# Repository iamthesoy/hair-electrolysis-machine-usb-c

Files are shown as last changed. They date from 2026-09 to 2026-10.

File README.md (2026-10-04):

# Hair Electrolysis Machine v4

### DIY electrolysis carries risk of permanent scarring if done improperly. If something goes wrong, only you are responsible.

electro2
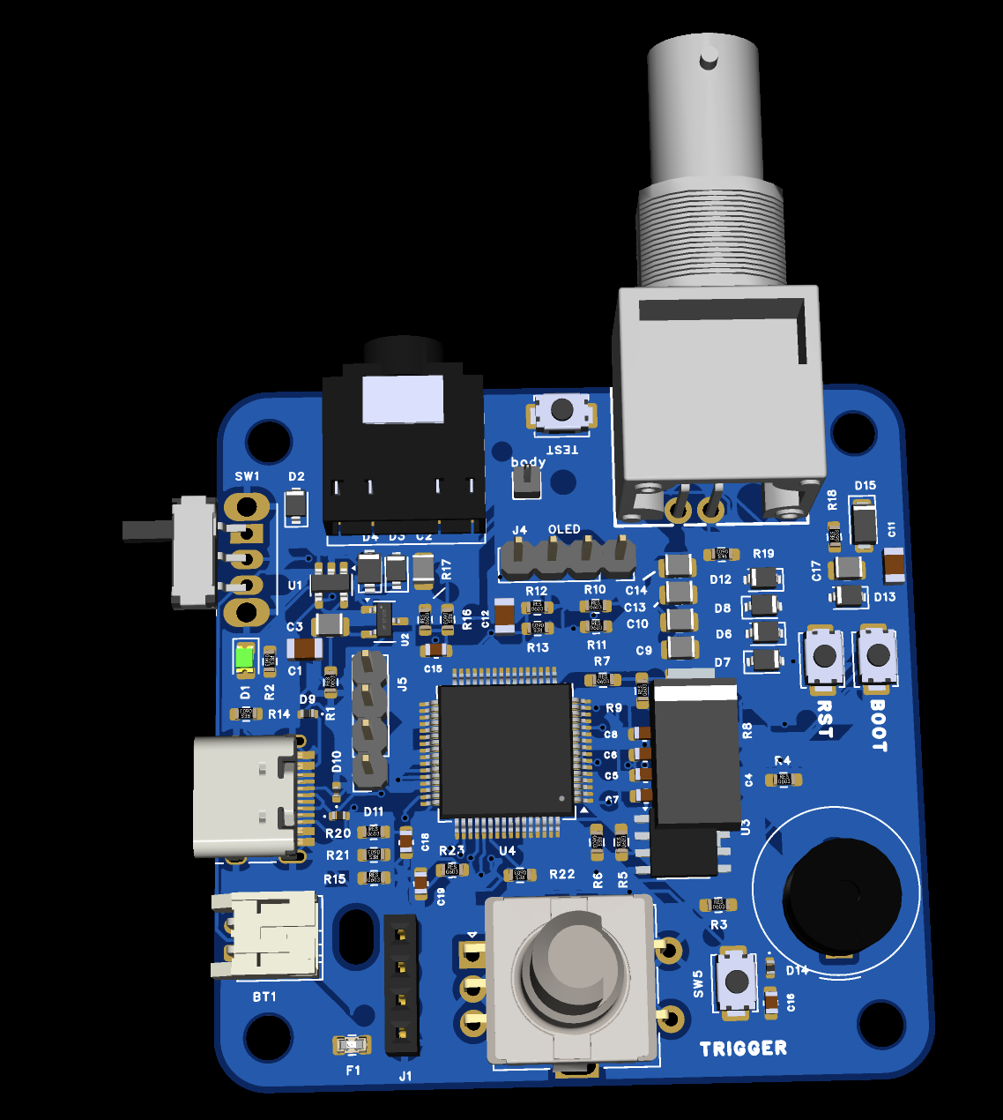
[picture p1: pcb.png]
electro3


---
This is a fork of zoemaestra's USB-C/STM32 fork of n3tcat's original. I've swapped a few connectors to make things sterex compatible as this is the hardware i'm used to, and uploaded some "compatible" sterex accessories for cost saving :) See zoe's readme below:

This is based on n3tcat's original design but redesigned around the STM32 to cut down the BOM and make the board single sided. Unlike v3.4, this board requires no soldering to assemble, just a 340mAh LiPo battery and a display which can just be plugged in. It is even cheaper and even easier to assemble at approximately £15/$20 per board!

You should really read the guide on how to order, assemble and use: https://imzoe.me/projects/electrolysis/electrolysis

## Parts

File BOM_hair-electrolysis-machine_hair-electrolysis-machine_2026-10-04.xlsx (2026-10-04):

No. | Quantity | Comment | Designator | Footprint | Value | Manufacturer Part | Manufacturer | Supplier Part | Supplier | LCSC
1 | 1 | HDR-M_2.54_1x1P | body | HDR-TH_1P-V-M_XKB_X4611WV-01I-C28D40
2 | 1 | Device_Battery_Cell | BT1 | Connector_JST:JST_PH_S2B-PH-K_1x02_P2.00mm_Horizontal | Battery_Cell |  |  |  |  | C16965
3 | 1 | Device_Buzzer | BZ1 | Buzzer_Beeper:Buzzer_TDK_PS1240P02BT_D12.2mm_H6.5mm | Buzzer |  |  |  |  | C76871
4 | 2 | Device_C_Small | C1,C5 | Capacitor_SMD:C_0603_1608Metric | 1uF |  |  |  |  | C15849
5 | 7 | Device_C | C2,C3,C9,C10,C13,C14,C17 | Capacitor_SMD:C_0805_2012Metric | 4.7uF |  |  |  |  | C1779
6 | 6 | Device_C_Small | C4,C6,C7,C8,C11,C16 | Capacitor_SMD:C_0603_1608Metric | 100nF |  |  |  |  | C14663
7 | 4 | Device_C | C12,C15,C18,C19 | Capacitor_SMD:C_0603_1608Metric | 100nF |  |  |  |  | C14663
8 | 1 | Device_LED | D1 | LED_SMD:LED_0805_2012Metric | LED |  |  |  |  | C84256
9 | 1 | Diode_SM4001 | D2 | Diode_SMD:D_SOD-323 | 1N4148WS |  |  |  |  | C2128
10 | 7 | Diode_1N5819WS | D3,D4,D6,D7,D8,D12,D13 | Diode_SMD:D_SOD-323 | 1N5819WS |  |  |  |  | C191023
11 | 2 | Diode_SMF18A | D5,D15 | Diode_SMD:D_SMF | SMF18A |  |  |  |  | C169433
12 | 4 | Diode_SM6T7V5A | D9,D10,D11,D14 | Diode_SMD:D_0402_1005Metric | ESD441 |  |  |  |  | C316049
13 | 1 | Device_Polyfuse | F1 | Fuse:Fuse_0805_2012Metric | 1A |  |  |  |  | C269104
14 | 4 | Mechanical_MountingHole | H1,H2,H3,H4 | MountingHole:MountingHole_3.2mm_M3 | MountingHole
15 | 1 | Mechanical_MountingHole | H5 | MountingHole:MountingHole_2.5mm | MountingHole
16 | 1 | Connector_Conn_01x04_Pin | J1 | Connector_PinHeader_2.54mm:PinHeader_1x04_P2.54mm_Vertical | Conn_01x04_Pin
17 | 1 | Connector_USB_C_Receptacle_USB2.0_16P | J2 | Connector_USB:USB_C_Receptacle_HRO_TYPE-C-31-M-12 | USB_C_Receptacle_USB2.0_16P |  |  |  |  | C165948
18 | 1 | Connector_Audio_AudioJack3_SwitchTR | J3 | Connector_Audio:Jack_3.5mm_CUI_SJ1-3525N_Horizontal | AudioJack2_Ground_Switch |  |  |  |  | C16684
19 | 2 | Connector_Conn_01x04_Pin | J4,J5 | Connector_PinSocket_2.54mm:PinSocket_1x04_P2.54mm_Vertical | Conn_01x04_Pin |  |  |  |  | C2718488
20 | 1 | 3GHz | probe | BNC-TH_DOSIN-801-0030 | 3GHz | DOSIN-801-0031 | dosinconn(德索五金) | C521205 | LCSC
21 | 1 | Transistor_FET_BSS138 | Q1 | Package_TO_SOT_SMD:SOT-23 | BSS138 |  |  |  |  | C8490
22 | 1 | Device_R | R1 | Resistor_SMD:R_0603_1608Metric | 2.7K |  |  |  |  | C13167
23 | 1 | Device_R | R2 | Resistor_SMD:R_0603_1608Metric | 1K |  |  |  |  | C21190
24 | 2 | Device_R | R3,R4 | Resistor_SMD:R_0603_1608Metric_Pad0.98x0.95mm_HandSolder | 100K1% |  |  |  |  | C25803
25 | 3 | Device_R | R5,R6,R7 | Resistor_SMD:R_0603_1608Metric_Pad0.98x0.95mm_HandSolder | 10K |  |  |  |  | C25804
26 | 2 | Device_R | R8,R9 | Resistor_SMD:R_0603_1608Metric_Pad0.98x0.95mm_HandSolder | 680R |  |  |  |  | C23228
27 | 3 | Device_R | R10,R11,R18 | Resistor_SMD:R_0603_1608Metric | 100R |  |  |  |  | C22775
28 | 2 | Device_R_Small | R12,R16 | Resistor_SMD:R_0603_1608Metric | 470K 1% |  |  |  |  | C23178
29 | 6 | Device_R_Small | R13,R17,R20,R21,R22,R23 | Resistor_SMD:R_0603_1608Metric | 100K 1% |  |  |  |  | C25803
30 | 2 | Device_R | R14,R15 | Resistor_SMD:R_0603_1608Metric | 5.1K |  |  |  |  | C23186
31 | 1 | Device_R | R19 | Resistor_SMD:R_0603_1608Metric_Pad0.98x0.95mm_HandSolder | 470R |  |  |  |  | C23179
32 | 1 | Switch_SW_SPDT | SW1 | Button_Switch_THT:SW_Slide_SPDT_Angled_CK_OS102011MA1Q | SW_SPDT |  |  |  |  | C131374
33 | 4 | Switch_SW_Push | SW2,SW3,SW5,TEST | Button_Switch_SMD:SW_SPST_TS-1088-xR025 | BTN |  |  |  |  | C720477
34 | 1 | Device_RotaryEncoder_Switch | SW4 | Rotary_Encoder:RotaryEncoder_Alps_EC11E-Switch_Vertical_H20mm | RotaryEncoder_Switch |  |  |  |  | C2991196
35 | 1 | Battery_Management_MCP73831-2-OT | U1 | Package_TO_SOT_SMD:SOT-23-5 | TP4054 |  |  |  |  | C668215
36 | 1 | Regulator_Linear_XC6206PxxxMR | U2 | Package_TO_SOT_SMD:SOT-23-3 | XC6206PxxxMR |  |  |  |  | C5446
37 | 1 | Amplifier_Operational_LM358 | U3 | Package_SO:SOIC-8_3.9x4.9mm_P1.27mm | LM358B |  |  |  |  | C1850238
38 | 1 | MCU_ST_STM32G0_STM32G0B1RBTx | U4 | Package_QFP:LQFP-64_10x10mm_P0.5mm | STM32G0B1RBTx |  |  |  |  | C5143679

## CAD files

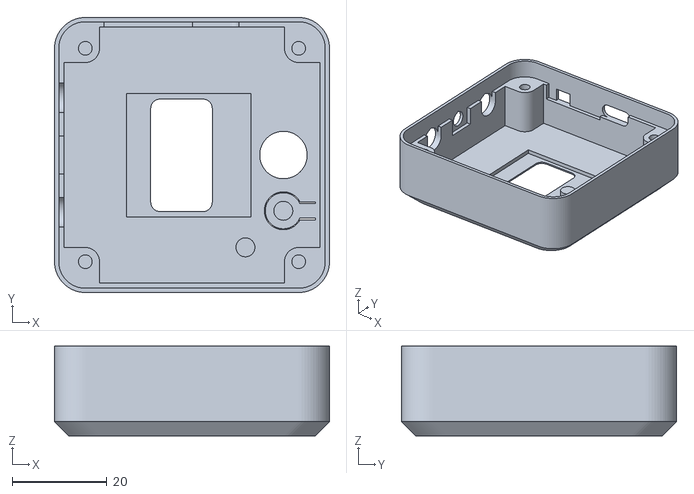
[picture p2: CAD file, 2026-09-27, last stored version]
3dprint/body_main.stl
58.0 x 58.0 x 18.9

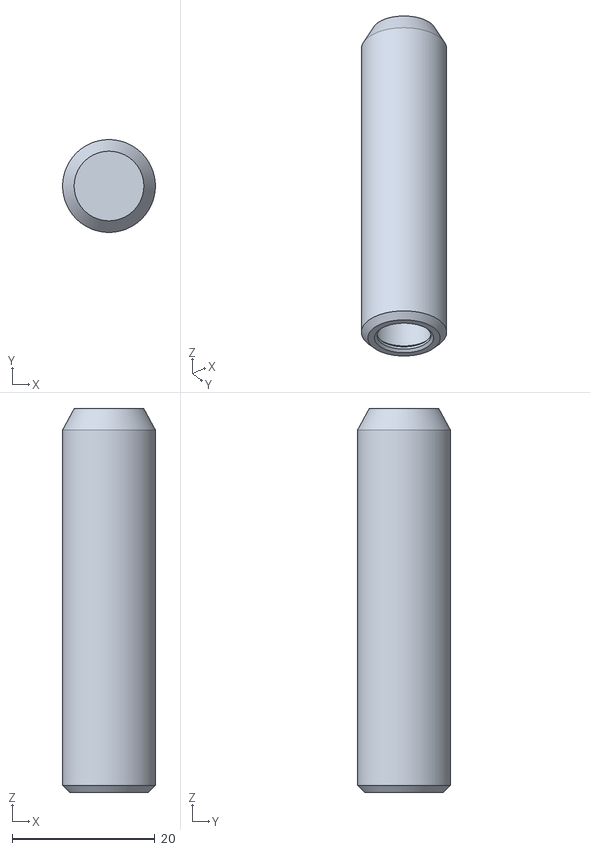
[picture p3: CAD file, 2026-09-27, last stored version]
3dprint/stylus_cap.stl
13.0 x 13.0 x 53.8

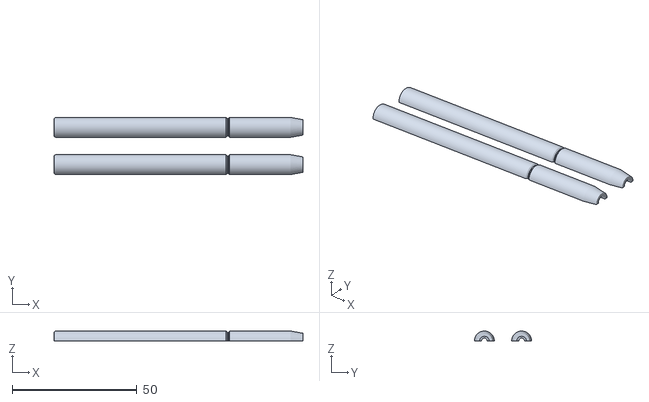
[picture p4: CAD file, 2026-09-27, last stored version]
3dprint/stylus_body.stl
100.0 x 23.0 x 4.00

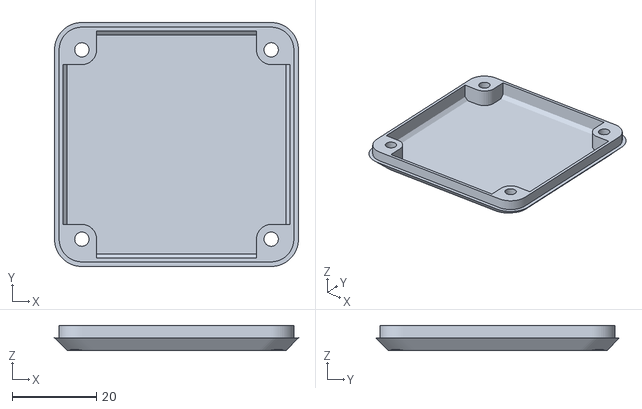
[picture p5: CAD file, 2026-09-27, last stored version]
3dprint/body_bottom.stl
58.0 x 58.0 x 6.00

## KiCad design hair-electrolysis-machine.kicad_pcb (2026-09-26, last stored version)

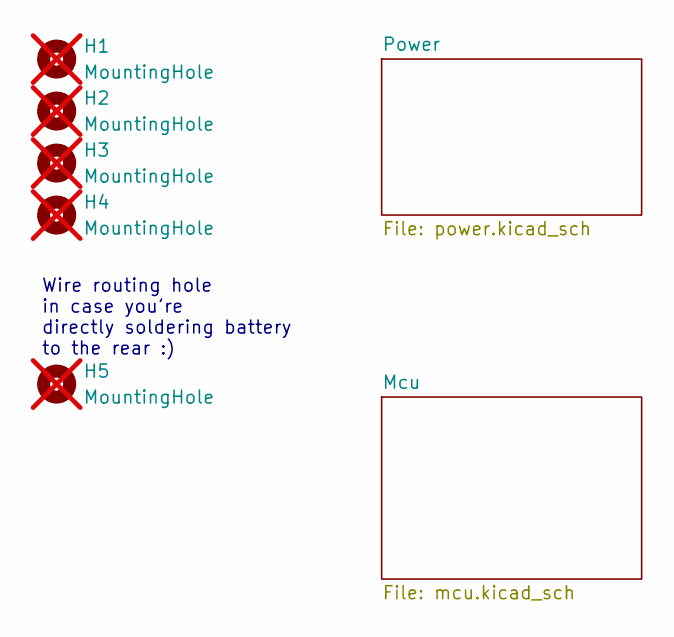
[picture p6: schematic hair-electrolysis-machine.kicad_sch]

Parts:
H1, H2, H3, H4: MountingHole; MountingHole_3.2mm_M3; not fitted
H5: MountingHole; MountingHole_2.5mm; not fitted

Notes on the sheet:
Wire routing hole in case you're directly soldering battery to the rear :)

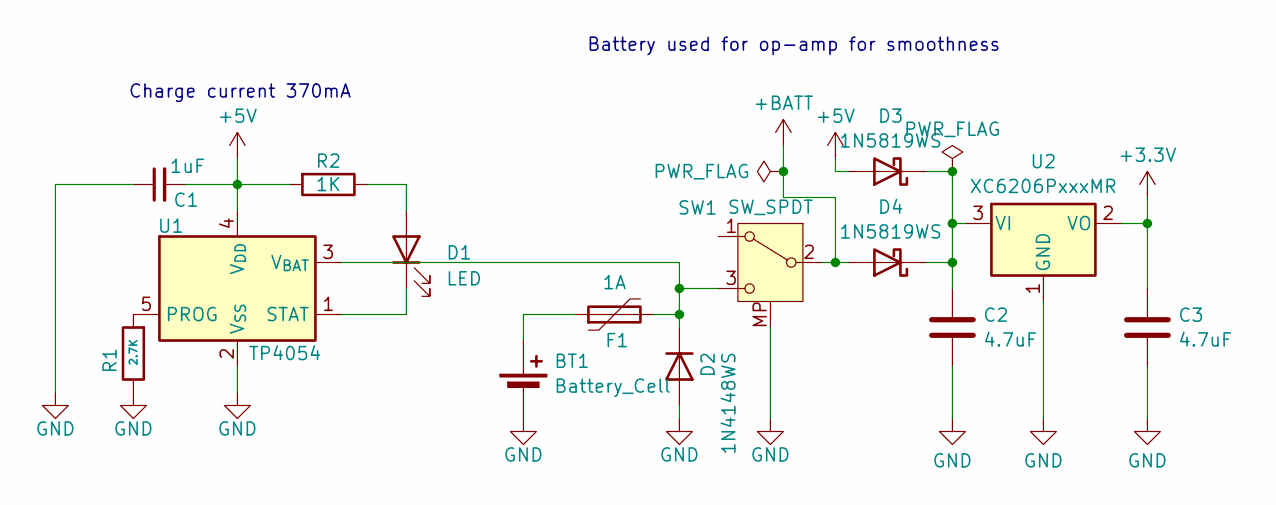
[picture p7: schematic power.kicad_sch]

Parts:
BT1: Battery_Cell; JST_PH_S2B-PH-K_1x02_P2.00mm_Horizontal; LCSC C16965
C1: 1uF; C_0603_1608Metric; LCSC C15849
C2, C3: 4.7uF; C_0805_2012Metric; LCSC C1779
D1: LED; LED_0805_2012Metric; LCSC C84256
D2: 1N4148WS; D_SOD-323; LCSC C2128
D3, D4: 1N5819WS; D_SOD-323; LCSC C191023
F1: 1A; Fuse_0805_2012Metric; LCSC C269104
R1: 2.7K; R_0603_1608Metric; LCSC C13167
R2: 1K; R_0603_1608Metric; LCSC C21190
SW1: SW_SPDT; SW_Slide_SPDT_Angled_CK_OS102011MA1Q; LCSC C131374
U1: TP4054; SOT-23-5; LCSC C668215
U2: XC6206PxxxMR; SOT-23-3; LCSC C5446

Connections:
+3.3V: C3.1, U2.2 (VO); also elsewhere on the board
+5V: C1.2, D3.2 (A), R2.2, U1.4 (V_{DD}); also elsewhere on the board
+BATT: D4.2 (A), SW1.2 (B); also elsewhere on the board
GND: BT1.2 (-), C1.1, C2.2, C3.2, D2.2 (A), R1.1, SW1.MP, U1.2 (V_{SS}), U2.1 (GND); also elsewhere on the board
unnamed: BT1.1 (+), F1.1
unnamed: D1.2 (A), R2.1
unnamed: D1.1 (K), U1.1 (STAT)
unnamed: D2.1 (K), F1.2, SW1.3 (C), U1.3 (V_{BAT})
unnamed: C2.1, D3.1 (K), D4.1 (K), U2.3 (VI)
unnamed: R1.2, U1.5 (PROG)

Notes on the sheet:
Charge current 370mA
Battery used for op-amp for smoothness

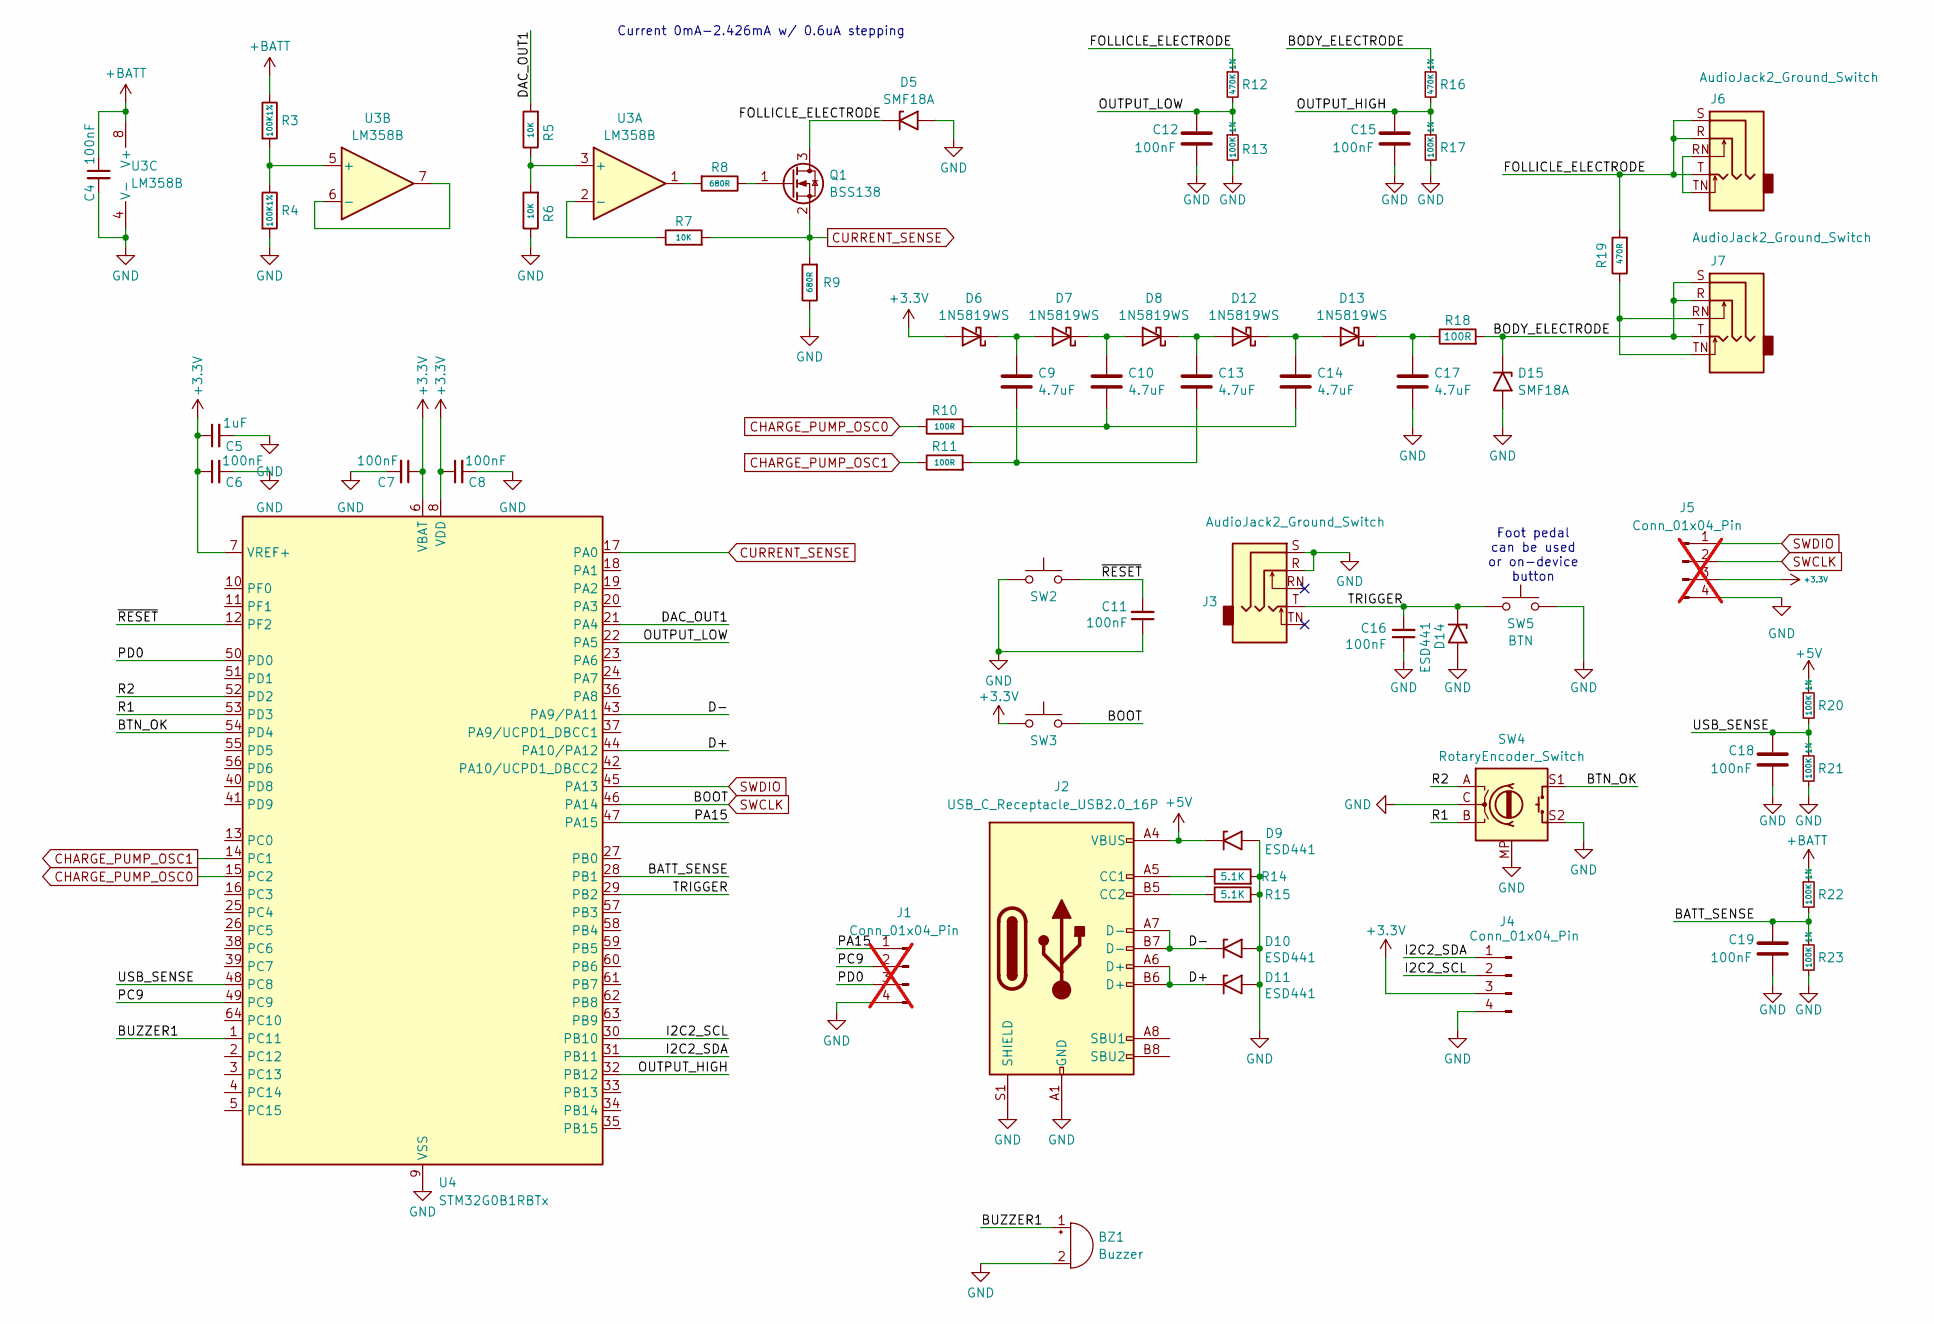
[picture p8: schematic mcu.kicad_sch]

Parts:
BZ1: Buzzer; Buzzer_TDK_PS1240P02BT_D12.2mm_H6.5mm; LCSC C76871
C4, C6, C7, C8, C11, C12, C15, C16, C18, C19: 100nF; C_0603_1608Metric; LCSC C14663
C5: 1uF; C_0603_1608Metric; LCSC C15849
C9, C10, C13, C14, C17: 4.7uF; C_0805_2012Metric; LCSC C1779
D5, D15: SMF18A; D_SMF; LCSC C169433
D6, D7, D8, D12, D13: 1N5819WS; D_SOD-323; LCSC C191023
D9, D10, D11, D14: ESD441; D_0402_1005Metric; LCSC C316049
J1: Conn_01x04_Pin; PinHeader_1x04_P2.54mm_Vertical; not fitted
J2: USB_C_Receptacle_USB2.0_16P; USB_C_Receptacle_HRO_TYPE-C-31-M-12; LCSC C165948
J3, J6: AudioJack2_Ground_Switch; Jack_3.5mm_CUI_SJ1-3525N_Horizontal; LCSC C16684
J4: Conn_01x04_Pin; PinSocket_1x04_P2.54mm_Vertical; LCSC C2718488
J5: Conn_01x04_Pin; PinSocket_1x04_P2.54mm_Vertical; not fitted
J7: AudioJack2_Ground_Switch; Jack_2.5mm_PJ242_6P_12x6.2x4mm_Horizontal; LCSC C431536
Q1: BSS138; SOT-23; LCSC C8490
R3, R4: 100K1%; R_0603_1608Metric_Pad0.98x0.95mm_HandSolder; LCSC C25803
R5, R6, R7: 10K; R_0603_1608Metric_Pad0.98x0.95mm_HandSolder; LCSC C25804
R8, R9: 680R; R_0603_1608Metric_Pad0.98x0.95mm_HandSolder; LCSC C23228
R10, R11, R18: 100R; R_0603_1608Metric; LCSC C22775
R12, R16: 470K 1%; R_0603_1608Metric; LCSC C23178
R13, R17, R20, R21, R22, R23: 100K 1%; R_0603_1608Metric; LCSC C25803
R14, R15: 5.1K; R_0603_1608Metric; LCSC C23186
R19: 470R; R_0603_1608Metric_Pad0.98x0.95mm_HandSolder; LCSC C23179
SW2, SW3, SW5: BTN; SW_SPST_TS-1088-xR025; LCSC C720477
SW4: RotaryEncoder_Switch; RotaryEncoder_Alps_EC11E-Switch_Vertical_H20mm; LCSC C2991196
U3: LM358B; SOIC-8_3.9x4.9mm_P1.27mm; LCSC C1850238
U4: STM32G0B1RBTx; LQFP-64_10x10mm_P0.5mm; LCSC C5143679

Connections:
+3.3V: C5.1, C6.1, C7.1, C8.1, D6.2 (A), J4.3, J5.3, SW3.2, U4.6 (VBAT), U4.7 (VREF+), U4.8 (VDD); also elsewhere on the board
+5V: D9.1 (A1), J2.A4 (VBUS), J2.A9 (VBUS), J2.B4 (VBUS), J2.B9 (VBUS), R20.1; also elsewhere on the board
+BATT: C4.1, R3.1, R22.1, U3.8 (V+); also elsewhere on the board
/Mcu/BATT_SENSE: C19.1, R22.2, R23.1, U4.28 (PB1)
/Mcu/BODY_ELECTRODE: D15.1 (A1), J7.R, J7.S, J7.T, R16.1, R18.2
/Mcu/BTN_OK: SW4.S1, U4.54 (PD4)
/Mcu/BUZZER1: BZ1.1 (+), U4.1 (PC11)
/Mcu/D+: D11.1 (A1), J2.A6 (D+), J2.B6 (D+), U4.44 (PA10/PA12)
/Mcu/D-: D10.1 (A1), J2.A7 (D-), J2.B7 (D-), U4.43 (PA9/PA11)
/Mcu/DAC_OUT1: R5.2, U4.21 (PA4)
/Mcu/FOLLICLE_ELECTRODE: D5.1 (A1), J6.R, J6.S, J6.T, Q1.3 (D), R12.1, R19.2
/Mcu/I2C2_SCL: J4.2, U4.30 (PB10)
/Mcu/I2C2_SDA: J4.1, U4.31 (PB11)
/Mcu/OUTPUT_HIGH: C15.1, R16.2, R17.1, U4.32 (PB12)
/Mcu/OUTPUT_LOW: C12.1, R12.2, R13.1, U4.22 (PA5)
/Mcu/PA15: J1.1, U4.47 (PA15)
/Mcu/PC9: J1.2, U4.49 (PC9)
/Mcu/PD0: J1.3, U4.50 (PD0)
/Mcu/R1: SW4.B, U4.53 (PD3)
/Mcu/R2: SW4.A, U4.52 (PD2)
/Mcu/TRIGGER: C16.2, D14.1 (A1), J3.T, SW5.2, U4.29 (PB2)
/Mcu/USB_SENSE: C18.1, R20.2, R21.1, U4.48 (PC8)
/Mcu/~RESET: C11.2, SW2.1, U4.12 (PF2)
CHARGE_PUMP_OSC0: R10.1, U4.15 (PC2)
CHARGE_PUMP_OSC1: R11.1, U4.14 (PC1)
CURRENT_SENSE: Q1.2 (S), R7.2, R9.2, U4.17 (PA0)
GND: BZ1.2 (-), C4.2, C5.2, C6.2, C7.2, C8.2, C11.1, C12.2, C15.2, C16.1, C17.2, C18.2, C19.2, D5.2 (A2), D9.2 (A2), D10.2 (A2), D11.2 (A2), D14.2 (A2), D15.2 (A2), J1.4, J2.A1 (GND), J2.A12 (GND), J2.B1 (GND), J2.B12 (GND), J2.S1 (SHIELD), J3.R, J3.S, J4.4, J5.4, R4.2, R6.1, R9.1, R13.2, R14.2, R15.2, R17.2, R21.2, R23.2, SW2.2, SW4.C, SW4.MP, SW4.S2, SW5.1, U3.4 (V-), U4.9 (VSS); also elsewhere on the board
unnamed: C10.2, C14.2, R10.2
unnamed: C9.2, C13.2, R11.2
unnamed: C9.1, D6.1 (K), D7.2 (A)
unnamed: C10.1, D7.1 (K), D8.2 (A)
unnamed: C13.1, D8.1 (K), D12.2 (A)
unnamed: C14.1, D12.1 (K), D13.2 (A)
unnamed: C17.1, D13.1 (K), R18.1
unnamed: J2.A5 (CC1), R14.1
unnamed: J2.B5 (CC2), R15.1
unnamed: J6.RN, J6.TN
unnamed: J7.RN, J7.TN, R19.1
unnamed: Q1.1 (G), R8.1
unnamed: R8.2, U3.1
unnamed: R5.1, R6.2, U3.3 (+)
unnamed: R7.1, U3.2 (-)
unnamed: R3.2, R4.1, U3.5 (+)
unnamed: U3.6 (-), U3.7
SWCLK: J5.2, SW3.1, U4.46 (PA14)
SWDIO: J5.1, U4.45 (PA13)

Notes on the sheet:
Current 0mA-2.426mA w/ 0.6uA stepping
Foot pedal can be used or on-device button

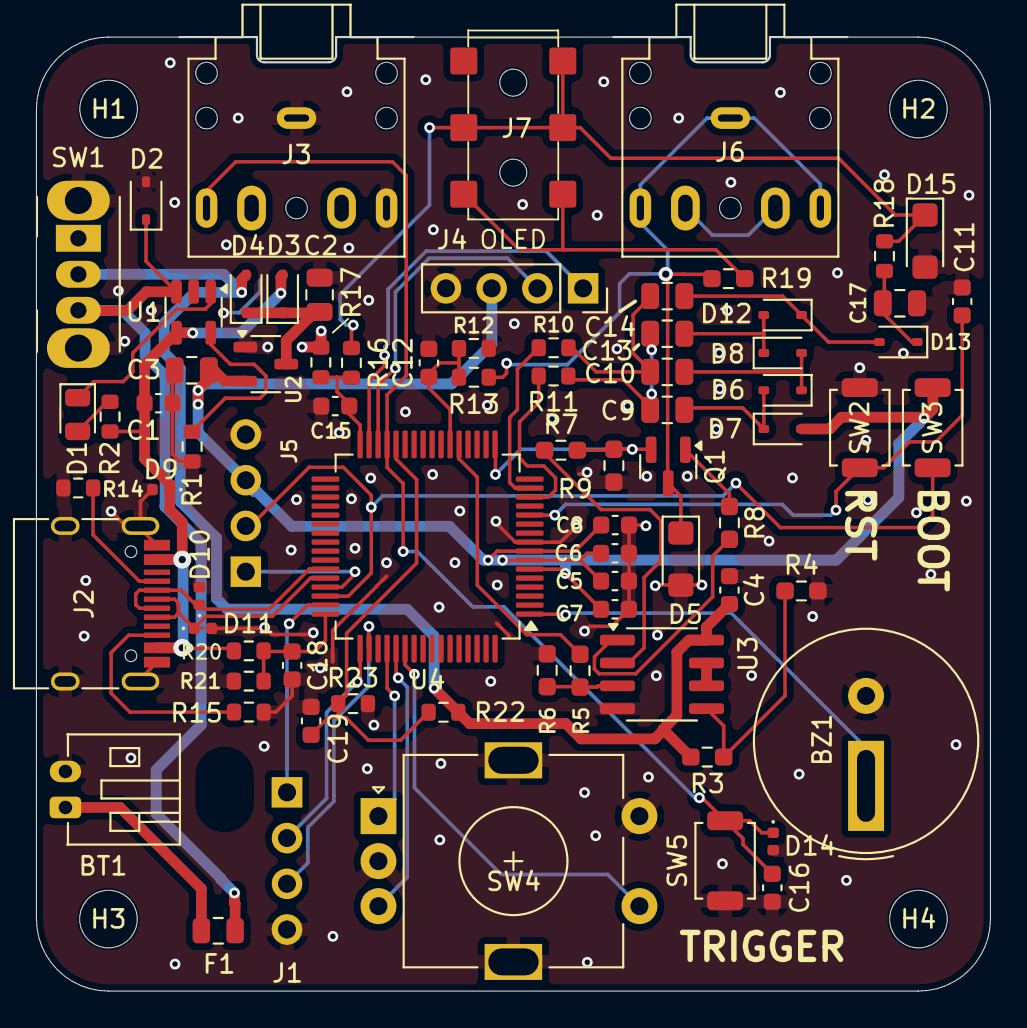
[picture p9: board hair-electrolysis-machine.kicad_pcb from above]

Board: 2 copper layers, 53.0 x 53.0 mm, 82 parts (0 on the bottom side), 52 nets.

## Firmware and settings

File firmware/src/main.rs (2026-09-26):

#![no_std]
#![no_main]

mod app;
mod button;
mod buzzer;
mod charge_pump;
mod current_dac;
mod gui;
mod meter;
mod output_handler;
mod safety;
mod settings;

use core::sync::atomic::Ordering;

use app::App;
use buzzer::{BUZZER_COMMAND_CHANNEL, Buzzer};
use charge_pump::ChargePump;
use current_dac::CurrentDac;
use embassy_executor::Spawner;
use embassy_futures::select::{Either, select};
use embassy_stm32::{
    bind_interrupts, dma,
    exti::{self, ExtiInput},
    flash::Flash,
    gpio::{Input, Pull},
    i2c::{self, I2c},
    peripherals::{DMA1_CH1, DMA1_CH2, I2C2},
};
use embassy_time::Timer;
use meter::Meter;
use output_handler::OutputHandler;
use portable_atomic::AtomicI32;
use safety::USB_CONNECTED;
use settings::SettingsStore;

use defmt_rtt as _;

bind_interrupts!(struct Irqs {
    I2C2_3 => i2c::EventInterruptHandler<I2C2>, i2c::ErrorInterruptHandler<I2C2>;
    DMA1_CHANNEL1 => dma::InterruptHandler<DMA1_CH1>;
    DMA1_CHANNEL2_3 => dma::InterruptHandler<DMA1_CH2>;
    EXTI2_3 => exti::InterruptHandler<embassy_stm32::interrupt::typelevel::EXTI2_3>;
});

static ENCODER_DELTA: AtomicI32 = AtomicI32::new(0);

#[embassy_executor::task]
async fn encoder(
    mut r1: ExtiInput<'static, embassy_stm32::mode::Async>,
    mut r2: ExtiInput<'static, embassy_stm32::mode::Async>,
) {
    let mut previous = ((r1.is_high() as u8) << 1) | r2.is_high() as u8;
    let mut steps = 0i8;

    loop {
        match select(r1.wait_for_any_edge(), r2.wait_for_any_edge()).await {
            Either::First(_) | Either::Second(_) => {}
        }

        // Contact debounce settling (1 ms)
        Timer::after_millis(1).await;
        let current = ((r1.is_high() as u8) << 1) | r2.is_high() as u8;
        const STEP: [i8; 16] = [0, -1, 1, 0, 1, 0, 0, -1, -1, 0, 0, 1, 0, 1, -1, 0];
        steps += STEP[((previous << 2) | current) as usize];
        previous = current;

        if steps <= -2 {
            ENCODER_DELTA.fetch_add(1, Ordering::Relaxed);
            steps = 0;
        } else if steps >= 2 {
            ENCODER_DELTA.fetch_add(-1, Ordering::Relaxed);
            steps = 0;
        }
    }
}

#[embassy_executor::task]
async fn buzzer_handler(mut buzzer: Buzzer<'static>) {
    loop {
        buzzer.play(BUZZER_COMMAND_CHANNEL.receive().await).await;
    }
}

#[embassy_executor::task]
async fn store_handler(mut store: SettingsStore<'static>) {
    store.tick_forever().await;
}

#[embassy_executor::task]
async fn output_task(mut handler: OutputHandler<'static>) {
    handler.tick_forever().await;
}

#[embassy_executor::task]
async fn usb_monitor(input: Input<'static>) {
    let mut stable = input.is_high();
    USB_CONNECTED.store(stable, Ordering::Relaxed);
    let mut count: u8 = 0;
    loop {
        let sample = input.is_high();
        if sample != stable {
            count += 1;
            if count >= 25 {
                // 50 ms of consistent new state required to switch
                stable = sample;
                USB_CONNECTED.store(stable, Ordering::Relaxed);
                count = 0;
            }
        } else {
            count = 0;
        }
        Timer::after_millis(2).await;
    }
}

#[embassy_executor::main]
async fn main(spawner: Spawner) {
    let mut config = embassy_stm32::Config::default();
    config.rcc.pll = Some(embassy_stm32::rcc::Pll {
        source: embassy_stm32::rcc::PllSource::HSI,
        prediv: embassy_stm32::rcc::PllPreDiv::DIV1,
        mul: embassy_stm32::rcc::PllMul::MUL8,
        divp: None,
        divq: None,
        divr: Some(embassy_stm32::rcc::PllRDiv::DIV2),
    });
    config.rcc.sys = embassy_stm32::rcc::Sysclk::PLL1_R;
    let p = embassy_stm32::init(config);

    let store = SettingsStore::new(Flash::new_blocking(p.FLASH)).await;
    spawner.spawn(store_handler(store)).unwrap();

    let r2 = ExtiInput::new(p.PD2, p.EXTI2, Pull::Up, Irqs);
    let r1 = ExtiInput::new(p.PD3, p.EXTI3, Pull::Up, Irqs);
    spawner.spawn(encoder(r1, r2)).unwrap();

    spawner
        .spawn(buzzer_handler(Buzzer::new(p.TIM1, p.PC11)))
        .unwrap();

    spawner
        .spawn(usb_monitor(Input::new(p.PC8, Pull::None)))
        .unwrap();

    let meter = Meter::new(p.ADC1, p.PA0, p.PB1, p.PA5, p.PB12);
    let dac = CurrentDac::new(p.DAC1, p.PA4);
    let pump = ChargePump::new(p.TIM15, p.PC1, p.PC2);
    spawner
        .spawn(output_task(OutputHandler::new(
            pump, dac, meter, p.PB2, p.IWDG,
        )))
        .unwrap();

    let mut i2c_config = i2c::Config::default();
    i2c_config.frequency = embassy_stm32::time::Hertz(400_000);
    let display_i2c = I2c::new(
        p.I2C2, p.PB10, p.PB11, p.DMA1_CH1, p.DMA1_CH2, Irqs, i2c_config,
    );
    let mut app = App::new(display_i2c, p.PD4).await;

    loop {
        app.scroll(ENCODER_DELTA.swap(0, Ordering::Relaxed)).await;
        app.render().await;
        Timer::after_millis(5).await;
    }
}

#[panic_handler]
fn panic(_info: &core::panic::PanicInfo) -> ! {
    // Reset immediately: peripheral reset states disable TIM15 and DAC1.
    cortex_m::peripheral::SCB::sys_reset()
}

#[cortex_m_rt::exception]
unsafe fn HardFault(_frame: &cortex_m_rt::ExceptionFrame) -> ! {
    cortex_m::peripheral::SCB::sys_reset()
}

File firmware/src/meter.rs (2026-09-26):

use embassy_stm32::{
    Peri,
    adc::{Adc, SampleTime, VREF_CALIB_MV, VrefInt},
    peripherals::{ADC1, PA0, PA5, PB1, PB12},
};

pub struct Meter<'a> {
    adc: Adc<'a, ADC1>,
    current: Peri<'a, PA0>,
    battery: Peri<'a, PB1>,
    output_low: Peri<'a, PA5>,
    output_high: Peri<'a, PB12>,
    vref: VrefInt,
}

impl<'a> Meter<'a> {
    pub fn new(
        adc: Peri<'a, ADC1>,
        current: Peri<'a, PA0>,
        battery: Peri<'a, PB1>,
        output_low: Peri<'a, PA5>,
        output_high: Peri<'a, PB12>,
    ) -> Self {
        let adc = Adc::new(adc);
        let vref = adc.enable_vrefint();
        Self {
            adc,
            current,
            battery,
            output_low,
            output_high,
            vref,
        }
    }

    fn vdda(&mut self) -> f64 {
        let raw = self
            .adc
            .blocking_read(&mut self.vref, SampleTime::CYCLES160_5);
        if raw == 0 {
            return 3.3;
        }
        VREF_CALIB_MV as f64 * self.vref.calibrated_value() as f64 / raw as f64 / 1000.0
    }

    fn read_voltage<P: embassy_stm32::adc::AdcChannel<ADC1>>(
        adc: &mut Adc<'a, ADC1>,
        pin: &mut P,
        vdda: f64,
    ) -> f64 {
        // average eight conversions here to reduce regulator and pump noise.
        let mut sum = 0u32;
        for _ in 0..8 {
            sum += adc.blocking_read(pin, SampleTime::CYCLES160_5) as u32;
        }
        (sum as f64 / 8.0) * vdda / 4095.0
    }

    pub fn battery_voltage(&mut self) -> f64 {
        let vdda = self.vdda();
        Self::read_voltage(&mut self.adc, &mut self.battery, vdda) * 2.0
    }

    pub fn charge_pump_voltage(&mut self) -> f64 {
        let vdda = self.vdda();
        Self::read_voltage(&mut self.adc, &mut self.output_high, vdda) * 5.7
    }

    pub fn low_side_voltage(&mut self) -> f64 {
        let vdda = self.vdda();
        Self::read_voltage(&mut self.adc, &mut self.output_low, vdda) * 5.7
    }

    pub fn delta_voltage(&mut self) -> f64 {
        self.charge_pump_voltage() - self.low_side_voltage()
    }

    pub fn measure_current_ma(&mut self) -> f64 {
        let vdda = self.vdda();
        Self::read_voltage(&mut self.adc, &mut self.current, vdda) / 0.680
    }
}

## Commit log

2026-09-26 Updated buzzer and jack detection
    [hair-electrolysis-machine.kicad_pcb, mcu.kicad_sch]
2026-09-26 dnp holes
    [hair-electrolysis-machine.kicad_sch]
2026-09-26 badly behaved bom
    [hair-electrolysis-machine.kicad_pcb]
2026-09-27 Upload 3d print files
    [body_bottom.stl, body_main.stl, stylus_body.stl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]
2026-09-28 Update README with purchase link for pre-assembled unit
    Added a link to purchase a pre-assembled unit with accessories.
2026-10-04 Delete 3dprint directory
    files to come
    [body_bottom.stl, body_main.stl, stylus_body.stl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]
